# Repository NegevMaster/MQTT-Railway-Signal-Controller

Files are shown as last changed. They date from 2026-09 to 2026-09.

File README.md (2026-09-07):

# MQTT Railway Signal Controller

A PlatformIO firmware project for an ESP32-based railway signal controller that drives multiple signal mast layouts over MQTT.

## Overview

This project listens for MQTT commands and updates railway signal lamps connected to PCA9685 boards. It is designed for a modular signal setup with support for standard signal states and distant-signal combinations.

## Features

- ESP32 firmware using Arduino/PlatformIO
- Wi-Fi + MQTT control
- PCA9685 PWM signal board support
- Flashing and steady LED states
- Signal status handling for main and distant signals
- Clean local configuration override for Wi‑Fi and MQTT credentials

## Hardware

- ESP32 development board
- One or more PCA9685 I2C PWM controllers
- Railway signal LEDs or LED modules on the PCA9685 outputs
- Wi‑Fi network and MQTT broker

## Repository layout

- `src/` – firmware entry points and signal logic
- `include/` – shared configuration and declarations
- `lib/` – project libraries (if added later)
- `test/` – test scaffolding
- `platformio.ini` – PlatformIO build configuration

## Setup

1. Copy the sample config file:
   ```bash
   copy include\config.local.h.example include\config.local.h
   ```
2. Edit `include/config.local.h` and fill in your local Wi‑Fi and MQTT values.
3. Build and upload:
   ```bash
   pio run -e esp32dev
   pio run -e esp32dev -t upload
   ```
4. Optionally monitor serial output:
   ```bash
   pio device monitor -e esp32dev
   ```

## MQTT topic structure

The firmware subscribes to topics under the base prefix defined in `config.h`:

```cpp
#define BASE_MQTT_TOPIC "trains/track/signalmast/"
```

Messages are expected to include the signal name and a display state such as `Sygnał S1`, `Sygnał S2`, and similar values used by the project.

## Security note

This repository intentionally does not include real credentials. Keep your personal Wi‑Fi and MQTT settings in `include/config.local.h`, which is ignored by Git.

## License

This project is licensed under the MIT License. See [LICENSE](LICENSE) for details.

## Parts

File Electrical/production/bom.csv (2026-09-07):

Designator | Footprint | Quantity | Value | LCSC Part #
C1, C2, C3 | 0805 | 3 | 100nF
D1 | LED_D3.0mm_FlatTop | 1 | GREEN
J1, J2, J3, J4 | JST_XH_B3B-XH-A_1x03_P2.50mm_Vertical | 4 | Conn_01x03_Socket
J10, J11, J8, J9 | JST_XH_B5B-XH-A_1x05_P2.50mm_Vertical | 4 | Conn_01x05_Socket
J12, J13, J14 | JST_XH_B6B-XH-A_1x06_P2.50mm_Vertical | 3 | Conn_01x06_Socket
J5, J6, J7 | JST_XH_B4B-XH-A_1x04_P2.50mm_Vertical | 3 | Conn_01x04_Socket
R1, R18, R2, R47, R54 | 0805 | 5 | 10K
R10, R11, R12, R13, R14, R15, R16, R17, R19, R20, R21, R22, R23, R24, R25, R26, R27, R28, R29, R3, R30, R31, R32, R33, R34, R35, R36, R37, R38, R39, R4, R40, R41, R42, R43, R44, R45, R46, R48, R49, R5, R50, R51, R52, R53, R6, R7, R8, R9 | 0805 | 49 | 1K
U1 | MCU_Seeed_ESP32C3 | 1 | ~
U2, U3, U4 | TSSOP-28_4.4x9.7mm_P0.65mm | 3 | PCA9685PW

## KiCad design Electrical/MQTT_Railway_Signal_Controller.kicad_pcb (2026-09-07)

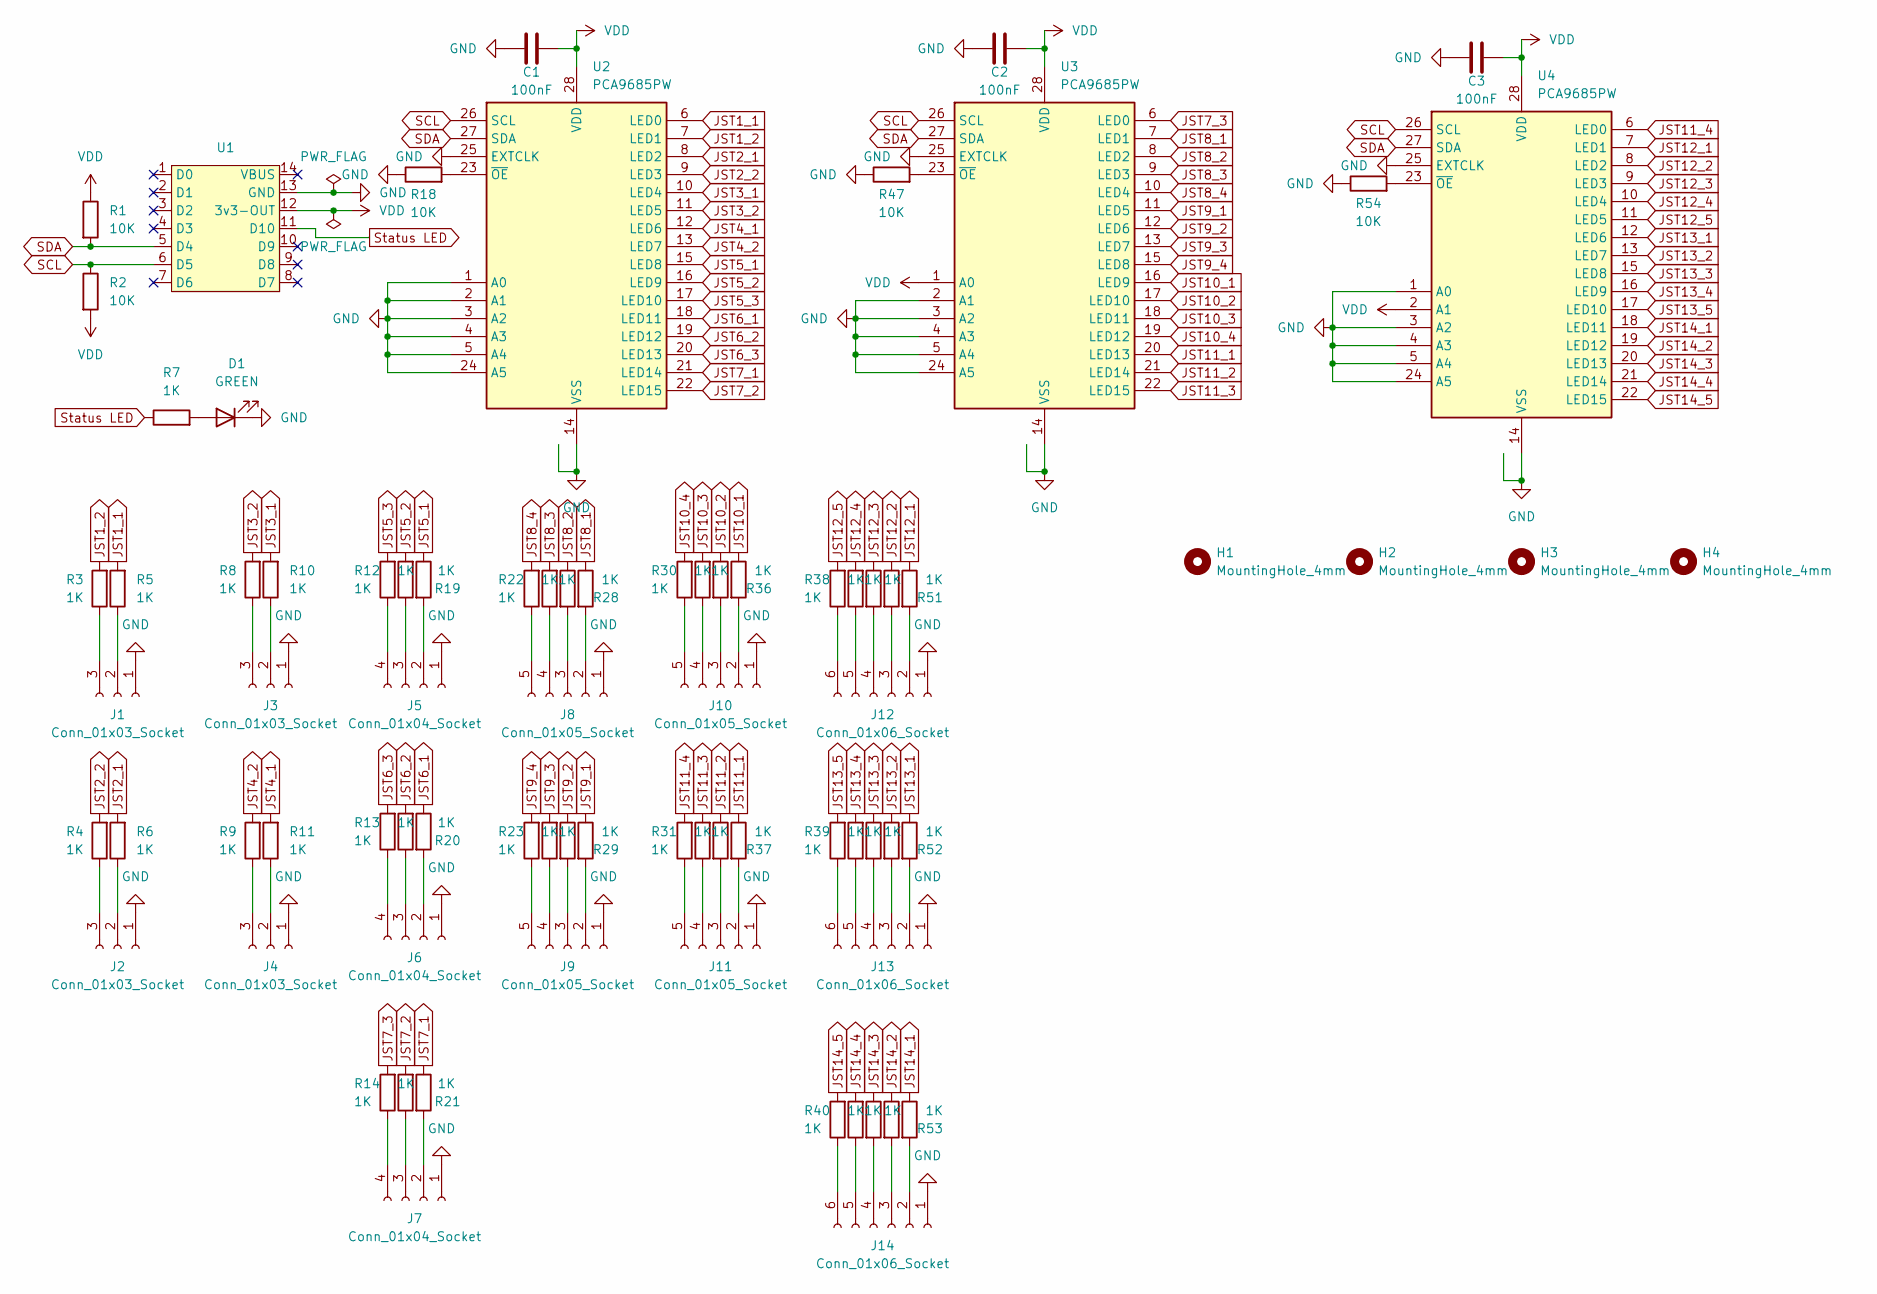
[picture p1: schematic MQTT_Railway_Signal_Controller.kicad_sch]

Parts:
C1, C2, C3: 100nF; C_0805_2012Metric
D1: GREEN; LED_D3.0mm_FlatTop
H1, H2, H3, H4: MountingHole_4mm
J1, J2, J3, J4: Conn_01x03_Socket; JST_XH_B3B-XH-A_1x03_P2.50mm_Vertical
J5, J6, J7: Conn_01x04_Socket; JST_XH_B4B-XH-A_1x04_P2.50mm_Vertical
J8, J9, J10, J11: Conn_01x05_Socket; JST_XH_B5B-XH-A_1x05_P2.50mm_Vertical
J12, J13, J14: Conn_01x06_Socket; JST_XH_B6B-XH-A_1x06_P2.50mm_Vertical
R1, R2, R18, R47, R54: 10K; R_0805_2012Metric
R3, R4, R5, R6, R7, R8, R9, R10, R11, R12, R13, R14, R15, R16, R17, R19, R20, R21, R22, R23, R24, R25, R26, R27, R28, R29, R30, R31, R32, R33, R34, R35, R36, R37, R38, R39, R40, R41, R42, R43, R44, R45, R46, R48, R49, R50, R51, R52, R53: 1K; R_0805_2012Metric
U1: MCU_Seeed_ESP32C3
U2, U3, U4: PCA9685PW; TSSOP-28_4.4x9.7mm_P0.65mm

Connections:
GND: C1.1, C2.1, C3.1, D1.1 (K), J1.1, J2.1, J3.1, J4.1, J5.1, J6.1, J7.1, J8.1, J9.1, J10.1, J11.1, J12.1, J13.1, J14.1, R18.1, R47.1, R54.1, U1.13 (GND), U2.1 (A0), U2.2 (A1), U2.3 (A2), U2.4 (A3), U2.5 (A4), U2.14 (VSS), U2.24 (A5), U2.25 (EXTCLK), U3.2 (A1), U3.3 (A2), U3.4 (A3), U3.5 (A4), U3.14 (VSS), U3.24 (A5), U3.25 (EXTCLK), U4.1 (A0), U4.3 (A2), U4.4 (A3), U4.5 (A4), U4.14 (VSS), U4.24 (A5), U4.25 (EXTCLK)
JST1_1: R5.2, U2.6 (LED0)
JST1_2: R3.2, U2.7 (LED1)
JST2_1: R6.2, U2.8 (LED2)
JST2_2: R4.2, U2.9 (LED3)
JST3_1: R10.2, U2.10 (LED4)
JST3_2: R8.2, U2.11 (LED5)
JST4_1: R11.2, U2.12 (LED6)
JST4_2: R9.2, U2.13 (LED7)
JST5_1: R19.1, U2.15 (LED8)
JST5_2: R15.2, U2.16 (LED9)
JST5_3: R12.2, U2.17 (LED10)
JST6_1: R20.1, U2.18 (LED11)
JST6_2: R16.2, U2.19 (LED12)
JST6_3: R13.2, U2.20 (LED13)
JST7_1: R21.1, U2.21 (LED14)
JST7_2: R17.2, U2.22 (LED15)
JST7_3: R14.2, U3.6 (LED0)
JST8_1: R28.1, U3.7 (LED1)
JST8_2: R26.1, U3.8 (LED2)
JST8_3: R24.2, U3.9 (LED3)
JST8_4: R22.2, U3.10 (LED4)
JST9_1: R29.1, U3.11 (LED5)
JST9_2: R27.1, U3.12 (LED6)
JST9_3: R25.2, U3.13 (LED7)
JST9_4: R23.2, U3.15 (LED8)
JST10_1: R36.1, U3.16 (LED9)
JST10_2: R34.1, U3.17 (LED10)
JST10_3: R32.2, U3.18 (LED11)
JST10_4: R30.2, U3.19 (LED12)
JST11_1: R37.1, U3.20 (LED13)
JST11_2: R35.1, U3.21 (LED14)
JST11_3: R33.2, U3.22 (LED15)
JST11_4: R31.2, U4.6 (LED0)
JST12_1: R51.1, U4.7 (LED1)
JST12_2: R48.1, U4.8 (LED2)
JST12_3: R44.1, U4.9 (LED3)
JST12_4: R41.2, U4.10 (LED4)
JST12_5: R38.2, U4.11 (LED5)
JST13_1: R52.1, U4.12 (LED6)
JST13_2: R49.1, U4.13 (LED7)
JST13_3: R45.1, U4.15 (LED8)
JST13_4: R42.2, U4.16 (LED9)
JST13_5: R39.2, U4.17 (LED10)
JST14_1: R53.1, U4.18 (LED11)
JST14_2: R50.1, U4.19 (LED12)
JST14_3: R46.1, U4.20 (LED13)
JST14_4: R43.2, U4.21 (LED14)
JST14_5: R40.2, U4.22 (LED15)
unnamed: D1.2 (A), R7.2
unnamed: J1.2, R5.1
unnamed: J1.3, R3.1
unnamed: J2.2, R6.1
unnamed: J2.3, R4.1
unnamed: J3.2, R10.1
unnamed: J3.3, R8.1
unnamed: J4.2, R11.1
unnamed: J4.3, R9.1
unnamed: J5.2, R19.2
unnamed: J5.3, R15.1
unnamed: J5.4, R12.1
unnamed: J6.2, R20.2
unnamed: J6.3, R16.1
unnamed: J6.4, R13.1
unnamed: J7.2, R21.2
unnamed: J7.3, R17.1
unnamed: J7.4, R14.1
unnamed: J8.2, R28.2
unnamed: J8.3, R26.2
unnamed: J8.4, R24.1
unnamed: J8.5, R22.1
unnamed: J9.2, R29.2
unnamed: J9.3, R27.2
unnamed: J9.4, R25.1
unnamed: J9.5, R23.1
unnamed: J10.2, R36.2
unnamed: J10.3, R34.2
unnamed: J10.4, R32.1
unnamed: J10.5, R30.1
unnamed: J11.2, R37.2
unnamed: J11.3, R35.2
unnamed: J11.4, R33.1
unnamed: J11.5, R31.1
unnamed: J12.2, R51.2
unnamed: J12.3, R48.2
unnamed: J12.4, R44.2
unnamed: J12.5, R41.1
unnamed: J12.6, R38.1
unnamed: J13.2, R52.2
unnamed: J13.3, R49.2
unnamed: J13.4, R45.2
unnamed: J13.5, R42.1
unnamed: J13.6, R39.1
unnamed: J14.2, R53.2
unnamed: J14.3, R50.2
unnamed: J14.4, R46.2
unnamed: J14.5, R43.1
unnamed: J14.6, R40.1
unnamed: R18.2, U2.23 (~OE)
unnamed: R47.2, U3.23 (~OE)
unnamed: R54.2, U4.23 (~OE)
SCL: R2.1, U1.6 (D5), U2.26 (SCL), U3.26 (SCL), U4.26 (SCL)
SDA: R1.2, U1.5 (D4), U2.27 (SDA), U3.27 (SDA), U4.27 (SDA)
Status LED: R7.1, U1.11 (D10)
VDD: C1.2, C2.2, C3.2, R1.1, R2.2, U1.12 (3v3-OUT), U2.28 (VDD), U3.1 (A0), U3.28 (VDD), U4.2 (A1), U4.28 (VDD)

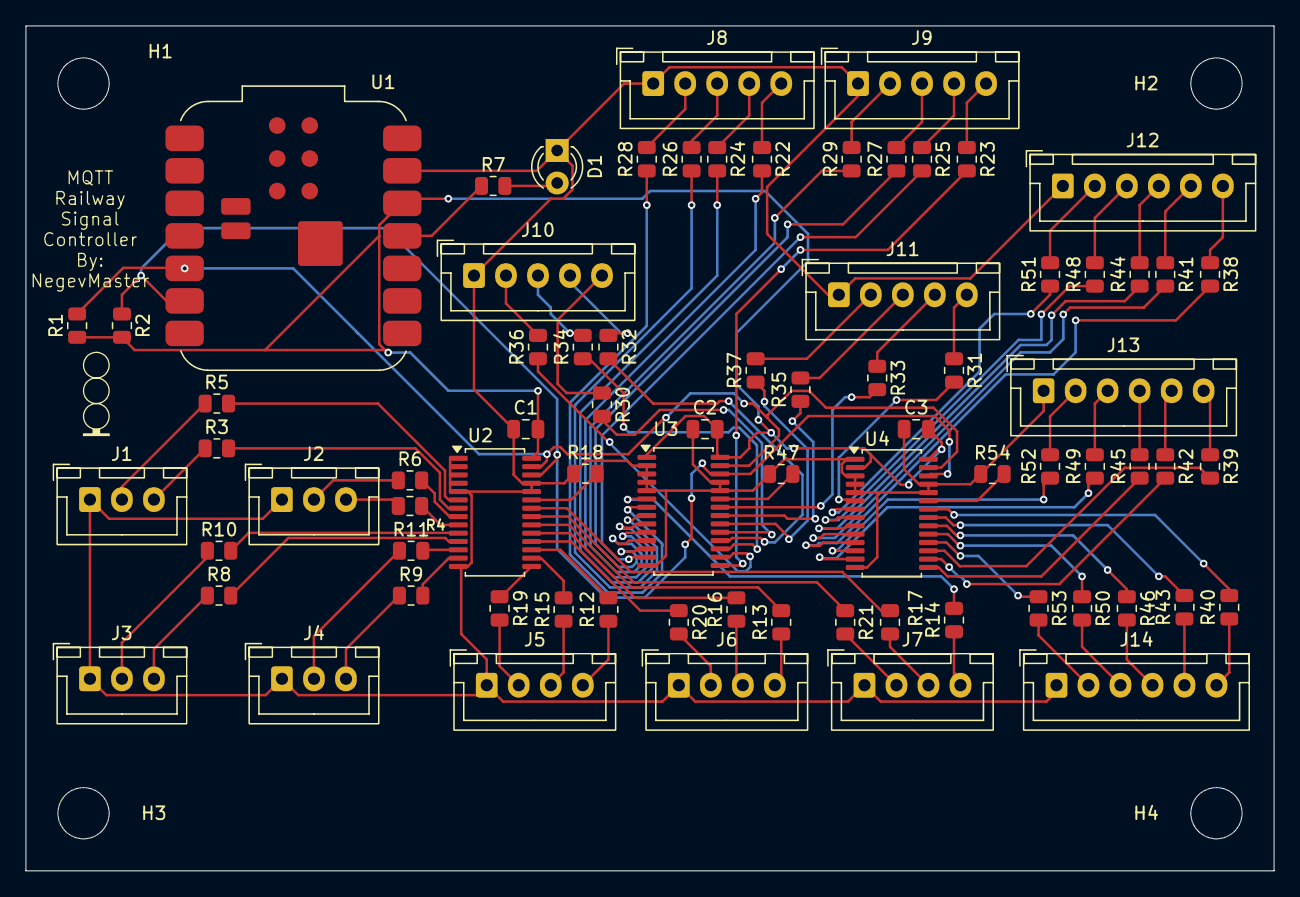
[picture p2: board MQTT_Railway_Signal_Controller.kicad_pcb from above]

Board: 2 copper layers, 97.5 x 66.0 mm, 80 parts (0 on the bottom side), 105 nets.

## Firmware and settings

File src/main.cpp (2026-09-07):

#include <Arduino.h>
#include <Wire.h>
#include <Adafruit_PWMServoDriver.h>
#include <WiFi.h>
#include <PubSubClient.h>
#include "config.h"
#include "structures.h"
#include "signals.h"
#include <string>
#include <cmath>

using namespace std;

WiFiClient espClient;
PubSubClient client(espClient);

Adafruit_PWMServoDriver pwmBoards[number_of_PCA9685];

void setup() {
  Serial.begin(115200);
  initializePCA9685Boards();
  pinMode(STATUS_LED_PIN, OUTPUT);
  delay(1000);

  WiFi.mode(WIFI_STA);
  WiFi.begin(Wifi_SSID, Wifi_Password);
  Serial.println("\nConnecting");

  while (WiFi.status() != WL_CONNECTED) {
    Serial.print(".");
    delay(100);
  }

  Serial.println("\nConnected to the WiFi network");
  Serial.print("Local Railway Controller IP:");
  Serial.println(WiFi.localIP());

  client.setServer(MQTT_BROKER, MQTT_PORT);
  client.connect(DEVICE_NAME, "", "", LAST_WILL_MQTT_TOPIC, 0, false, "OFFLINE");
  client.publish(LAST_WILL_MQTT_TOPIC, "ONLINE", true);
  client.setCallback(MessageReceiving);
  delay(1000);
  subscribingToSignals();
}

void loop() {
  updateFlashingLEDs();
  digitalWrite(STATUS_LED_PIN, true);

  if (!client.connected()) {
    digitalWrite(STATUS_LED_PIN, false);
    reconnect();
    client.publish(LAST_WILL_MQTT_TOPIC, "ONLINE");
    subscribingToSignals();
  }

  if (!client.loop()) {
    client.connect(DEVICE_NAME, "", "", LAST_WILL_MQTT_TOPIC, 0, false, "OFFLINE");
  }
}

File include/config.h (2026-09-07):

#ifndef CONFIG_H
#define CONFIG_H

#if __has_include("config.local.h")
#include "config.local.h"
#else
#define Wifi_SSID "YOUR_WIFI_SSID"
#define Wifi_Password "YOUR_WIFI_PASSWORD"
#define MQTT_BROKER "192.168.1.10"
#define MQTT_PORT 1883
#define MQTT_USER ""
#define MQTT_PASSWORD ""
#endif

#define USE_BUILTINLED_FOR_STATUS false
#define STATUS_LED_PIN 10

#define LAST_WILL_MQTT_TOPIC "trains/status/mqtt_signal_controller"
#define BASE_MQTT_TOPIC "trains/track/signalmast/"

#define DEVICE_NAME "MQTT_Signal_Controller"

#include <stdint.h>

#ifndef NUM_PCA9685
#define NUM_PCA9685 3
#endif

#ifndef DEVICE_SDA_PIN
#define DEVICE_SDA_PIN 21
#endif

#ifndef DEVICE_SCL_PIN
#define DEVICE_SCL_PIN 22
#endif

#define number_of_PCA9685 NUM_PCA9685
const uint8_t adressesPCA9685[number_of_PCA9685] = {0x40, 0x41, 0x42};

#define SDA_PIN DEVICE_SDA_PIN
#define SCL_PIN DEVICE_SCL_PIN
#define I2C_FREQ 100000

#endif

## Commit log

2026-09-07 Add initial project files for MQTT Railway Signal Controller
    - Create positions.csv for signal positions and configurations.
    - Add LICENSE file with MIT License terms.
    - Introduce README.md with project overview, features, hardware requirements, setup instructions, and MQTT topic structure.
    - Include example configuration file config.local.h.example for Wi-Fi and MQTT settings.
    [MQTT_Railway_Signal_Controller.kicad_pcb, MQTT_Railway_Signal_Controller.kicad_sch, bom.csv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]
2026-09-07 Update I2C pin definitions and modify board configuration for ESP32-C3
2026-09-07 Refactor I2C configuration and update PCA9685 address definitions in config.h and platformio.ini
